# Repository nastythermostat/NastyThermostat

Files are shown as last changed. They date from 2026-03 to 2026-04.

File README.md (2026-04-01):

# NastyThermostat

**Mechanically control a Nest Gen2 thermostat — fully local, no cloud, no API.**

A Nest Gen2 thermostat that lost Google connectivity? NastyThermostat gives it a second life by physically rotating the dial using a stepper motor and GT2 belt — controlled by an ESP32-C6 with MQTT, Domoticz, and Home Assistant integration.

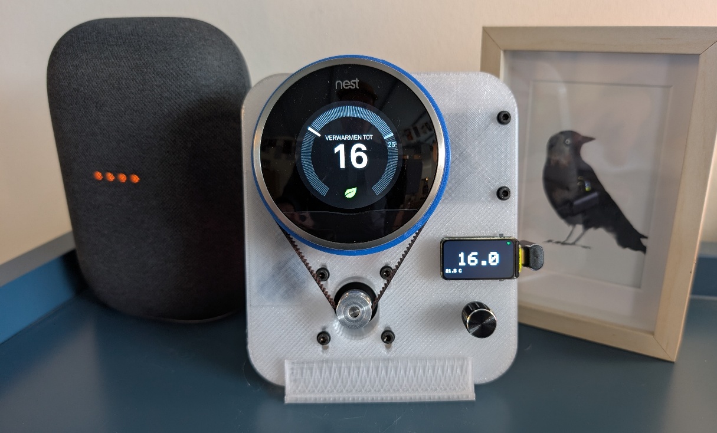
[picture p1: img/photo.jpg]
NastyThermostat hardware overview


▶️ **[Watch the video](https://youtu.be/sp1l5ZTAiks)**

---

## How it works

```
ESP32-C6  →  DRV8825 driver  →  NEMA17 stepper  →  GT2 belt  →  Nest dial
```

The ESP32-C6 reads a DS18B20 temperature sensor and receives setpoints via rotary encoder, MQTT, or HTTP API. It calculates how many steps to move and physically rotates the Nest dial to the target temperature.

---

## Quick start

| Step | Guide |
|---|---|
| **Assemble the hardware** | [→ Build guide](https://nastythermostat.cc/build) |
| **Print the 3D parts** | [→ 3D models](https://nastythermostat.cc/3d-models) |
| **Flash the firmware** | [→ Webflash (browser, no software needed)](https://nastythermostat.cc/webflash) |
| **Configure WiFi, MQTT & settings** | [→ Setup guide](https://nastythermostat.cc/setup) |
| **See it in action** | [→ YouTube video](https://youtu.be/sp1l5ZTAiks) |

---

## Features

- DS18B20 local temperature sensor
- Rotary encoder for manual control
- ST7789 TFT display (1.47")
- MQTT publish/subscribe (temperature + setpoint)
- Domoticz integration (IDX based)
- Home Assistant MQTT Discovery (automatic `climate` entity)
- HTTP REST API
- WiFiManager configuration portal (no code changes needed)
- Persistent settings (ESP32 Preferences)
- Stepper power management (auto-disable when idle)

---

## Parts list

**[→ Download full parts list with supplier links (Excel)](https://github.com/nastythermostat/NastyThermostat/raw/main/docs/Part_List.xlsx)**  
**[→ Build guide — wiring and assembly details](https://nastythermostat.cc/build)**

| # | Component | Qty | ~Price |
|---|---|---|---|
| 1 | ESP32-C6 dev board with 1.47" ST7789 display | 1 | €15.89 |
| 2 | DRV8825 stepper driver module | 1 | €1.69 |
| 3 | Stepper driver expansion board (4-channel) | 1 | €1.01 |
| 4 | NEMA17 stepper motor (1.8°, 17 Ncm, 1A, 23mm) | 1 | €9.76 |
| 5 | DS18B20 temperature sensor module | 1 | €1.83 |
| 6 | KY-040 rotary encoder | 1 | €1.55 |
| 7 | GT2 closed loop belt 320mm | 1 | €1.89 |
| 8 | GT2 pulley 20T, 5mm bore | 1 | €1.00 |
| 9 | 12V 3A power adapter (5.5×2.1mm) | 1 | €11.68 |
| 10 | DC-DC buck converter 12V → 5V 5A | 1 | €1.89 |
| 11 | USB-C 90° adapter | 1 | €2.25 |
| 12–15 | Cables (power, Dupont, stepper, USB-C/Micro-USB) | — | €6.79 |
| 16–18 | M3×8 screws, M3 washers, M2×8 screws | — | — |
| 19–21 | 3D printed: Nest pulley (138T), mounting plate, stand | — | — |

**Total electronics + mechanical: ~€55**

---

## Pin mapping

| Function | GPIO |
|---|---|
| TFT CS | 14 |
| TFT DC | 15 |
| TFT RST | 21 |
| TFT Backlight | 22 |
| TFT MOSI | 6 |
| TFT SCLK | 7 |
| Stepper STEP | 2 |
| Stepper DIR | 3 |
| Stepper ENABLE | 5 |
| Encoder CLK | 0 |
| Encoder DT | 1 |
| Encoder Button | 4 |
| DS18B20 | 9 |

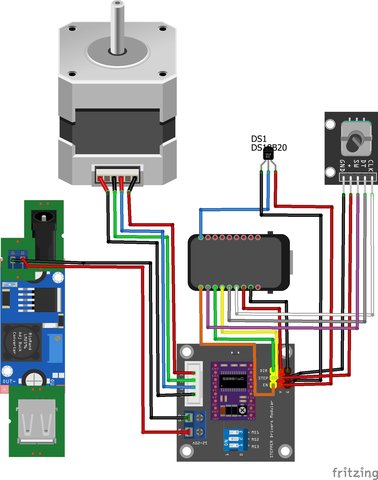
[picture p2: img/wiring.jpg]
Wiring diagram


---

## 3D printed parts

**[→ 3D models page with previews and download](https://nastythermostat.cc/3d-models)**  
**[→ Printables](https://www.printables.com/model/1659567-nastythermostat-3d-printed-parts-for-nest-gen2-ste)**  
**[→ Thingiverse](https://www.thingiverse.com/thing:7327205)**

STL files are in the [`/3d-models/`](3d-models/) folder. Print in PLA or PETG, 30% infill minimum.

| Part | Description |
|---|---|
| Nest pulley 138T | Attaches directly to the Nest dial ring |
| Motor mount | Mounts the NEMA17 to the base plate |
| Mounting plate | Base for all electronics and the Nest |
| Stand | Tilts the plate to the right angle |

---

## Flashing the firmware

**[→ Flash NastyThermostat via browser (no software needed)](https://nastythermostat.cc/webflash)**  
**[→ Full setup instructions](https://nastythermostat.cc/setup)**

The easiest way is via the browser — no software needed. Or build and upload with PlatformIO:

```bash
git clone https://github.com/nastythermostat/NastyThermostat.git
cd NastyThermostat
cp include/SecretsTemplate.h include/arduino_secrets.h
pio run --target upload
```

---

## Configuration

### First boot — WiFiManager portal

On first boot (or when WiFi is not found), the device creates an access point:

```
SSID:  NastyThermostatXXXXXX
URL:   http://192.168.4.1
```

Connect to this AP and open the portal to configure all settings.

| Setting | Description |
|---|---|
| **Device name** | Used for MQTT topics and AP SSID. Default: `NastyThermostatXXXXXX` |
| **MQTT server** | IP or hostname of your broker. Leave empty to disable MQTT. |
| **MQTT port** | Default: `1883` |
| **Domoticz IDX temperature** | Virtual sensor IDX for temperature. `0` = disabled. |
| **Domoticz IDX setpoint** | Virtual sensor IDX for setpoint. `0` = disabled. |
| **Domoticz gateway OUT mode** | `index` (default) = `domoticz/out/{idx}`. `flat` = `domoticz/out`, filtered by IDX. |
| **Homing after receiving setpoint** | `on` = full homing before move (accurate). `off` = small jiggle (faster, less wear). |
| **Home Assistant MQTT Discovery** | `on` = auto-creates a climate entity in HA. |
| **HTTP API token** | Required for POST requests. Leave empty to disable writes. |
| **MQTT publish interval** | How often temperature is published (seconds). Default: `30`. |

**[→ Full setup instructions with screenshots](https://nastythermostat.cc/setup)**

Re-open the portal anytime: **Menu → 5. WiFi setup → Start WiFi portal**, or hold the encoder button for 5 seconds at boot.

---

## MQTT topics

Topics use the device name (configurable in portal). Default: `NastyThermostatXXXXXX`

| Topic | Direction | Description |
|---|---|---|
| `{deviceName}/out/temp` | Publish | Current temperature (°C) |
| `{deviceName}/out/setpoint` | Publish (retained) | Current setpoint (°C) |
| `{deviceName}/in/setpoint` | Subscribe | Set new setpoint (float, e.g. `21.5`) |
| `{deviceName}/out/availability` | Publish (retained) | `online` / `offline` (LWT) |
| `{deviceName}/out/action` | Publish (retained) | `heating` or `idle` |
| `{deviceName}/out/mode` | Publish (retained) | `heat` (fixed, for HA compatibility) |

### Domoticz

```
Subscribe: domoticz/out/{idxSetpoint}   (index mode, default)
           domoticz/out                  (flat mode, filtered by idx)
Publish:   domoticz/in
```

### Home Assistant

With MQTT Discovery enabled, a `climate` entity is automatically created — no manual YAML needed.

---

## HTTP API

The device hosts a REST API on port 80.

### GET /api

```bash
curl http://192.168.x.x/api
```

```json
{
  "device_name": "NastyThermostat123456",
  "setpoint": 20.5,
  "temperature": 19.8,
  "offset": 0.0,
  "stepSize": 0.1,
  "motor_position": 14420,
  "steps_per_degree": 856.0,
  "mqtt_enabled": true
}
```

### POST /api

Requires token (set in WiFiManager portal).

```bash
curl -X POST http://192.168.x.x/api \
  -H "Content-Type: application/json" \
  -d '{"token":"yourtoken","setpoint":21.0}'
```

| Field | Type | Description |
|---|---|---|
| `token` | string | **Required**. API token from portal. |
| `setpoint` | float | New setpoint in °C (9.0–32.0) |
| `offset` | float | Temperature offset correction (−10.0 to 10.0) |
| `stepSize` | float | Encoder step size: `0.1`, `0.2`, `0.5` or `1.0` |
| `steps_per_degree` | float | Calibration: microsteps per °C (10–2000) |

---

## On-device menu

Press the encoder button to open the menu. Rotate to navigate, press to select.

| Item | Description |
|---|---|
| 1. Homing | Perform manual homing (moves to mechanical stop, resets position to 0) |
| 2. Temperature offset | Correct DS18B20 reading ±10°C, press to save |
| 3. Steps/degree | Calibration: microsteps per °C, press to save |
| 4. Step size | Encoder resolution: 0.1 / 0.2 / 0.5 / 1.0°C |
| 5. WiFi setup | Open WiFiManager portal (device reboots into AP mode) |
| 6. Status | Shows firmware version, IP address, MQTT status |
| 7. Back | Return to main screen |

---

## Display

The main screen shows:
- **Large center**: current setpoint (°C)
- **Bottom left**: measured temperature (°C)
- **Top right**: WiFi status icon — green = connected, red = disconnected
- **Background**: orange when heating (setpoint > temperature), black when idle

Screen auto-off after 15 seconds of inactivity. Encoder movement or motor activity wakes the display.

---

## Calibration

Default: **856 microsteps/°C** (= 26.75 full-steps, based on 138T/20T pulley ratio at 1/32 microstepping).

If your Nest doesn't hit the right temperatures, adjust via:
- On-device menu → **3. Steps/degree**
- HTTP API: `{"token":"...","steps_per_degree": 856.0}`

---

## Serial commands

Connect at **115200 baud**.

| Command | Description |
|---|---|
| `?` or `h` | Show status banner (IP, MQTT broker, topics) |
| `i` | Show WiFi and MQTT connection status |

---

## Troubleshooting

**Motor moves but Nest temperature is wrong**  
→ Adjust Steps/degree in menu or via API. Start with small increments.

**WiFi not connecting**  
→ Check Serial Monitor at 115200 baud. Re-open portal via menu → **5. WiFi setup**.

**MQTT not connecting**  
→ Verify broker IP and port in portal. Check Serial Monitor output.

**DS18B20 reads 0°C or wrong temperature**  
→ Check wiring on GPIO9. Use temperature offset in menu to correct.

**[→ Setup guide — more help and troubleshooting](https://nastythermostat.cc/setup)**

---

## License

MIT — see [LICENSE](LICENSE)

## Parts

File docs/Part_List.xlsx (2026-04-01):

Item No. | Category | Component Name | Description | Quantity | Unit Price (€) | Notes | Info/Link | Supplier
1 | Electronics | ESP32-C6 LCD 1.47 | ESP32-C6 dev board with 1.47” Waveshare | 1 | €15.89 | Main controller | https://www.waveshare.com/esp32-c6-lcd-1.47.htm | Amazon/AliExpress (https://nl.aliexpress.com/item/1005008207326324.html)
2 | Electronics | DRV8825 Stepper Driver | Microstepping driver module (heatsink included) | 1 | €1.69 | Stepper driver | AliExpress (https://nl.aliexpress.com/item/1005009949890484.html) | Amazon/AliExpress (https://www.amazon.nl/DollaTek-Stappenmotor-StepStick-stappenmotor-3D-printer/dp/B07DK6QMKG/)
3 | Electronics | Stepper Driver Expansion Board | 4-channel driver carrier board | 1 | €1.01 | 5V & GND distribution | AliExpress (https://nl.aliexpress.com/item/1005006070691966.html) | Amazon/AliExpress
4 | Electronics | NEMA17 Stepper Motor | 1.8°, 17 Ncm, 1A, 23mm body length | 1 | €9.76 | Compact motor | Amazon.nl (https://www.amazon.nl/dp/B0B93PNYCP?ref_=ppx_hzsearch_conn_dt_b_fed_asin_title_1) | Amazon/AliExpress
5 | Electronics | DS18B20 Temperature Sensor | Digital 1-Wire temperature module | 1 | €1.83 | Room temperature | AliExpress (https://nl.aliexpress.com/item/1005009580730409.html) | Amazon/AliExpress
6 | Electronics | KY-040 Rotary Encoder | 360° encoder with push button | 1 | €1.55 | User control | AliExpress (https://nl.aliexpress.com/item/1005009578504178.html) | Amazon/AliExpress
7 | Mechanical | GT2 Belt 320mm | Closed loop 2GT-320-6mm belt | 1 | €1.89 | Final belt length | AliExpress (https://nl.aliexpress.com/item/1005008778076494.html) | Amazon/AliExpress
8 | Mechanical | GT2 Pulley 20T | 20 teeth pulley, 5mm bore | 1 | €1.00 | On stepper motor | AliExpress (https://nl.aliexpress.com/item/32434506931.html) | Amazon/AliExpress
9 | Power | 12V 3A Power Adapter | 5.5x2.1mm DC output adapter | 1 | €11.68 | Main supply | Amazon.nl | Amazon/AliExpress
10 | Power | DC-DC Buck Converter | 12V to 5V 5A step-down module | 1 | €1.89 | Powers ESP32 | Amazon.nl (https://www.amazon.nl/Heemol-Converter-Module-Step-Down-Voeding/dp/B0BCV6GRH5) | Amazon/AliExpress
11 | Power | Adapter USB-C 90° Adapter | Power the ESP32 | 1 | €2.25 | Powers ESP32 | AliExpress (https://nl.aliexpress.com/item/1005007802183944.html) | Amazon/AliExpress
12 | Wiring | 12V Power Cable (thick) | 14cm red/black cable for stepper 12V supply | 1 | €1.00 | Adapter → driver |  | Amazon/AliExpress
13 | Wiring | Dupont Jumper Wires pack | 10 cm Female to Female | 1 | €1.50 | GND wiring | Amazon.nl (https://www.amazon.nl/dp/B0BJDW1S4Z?ref=ppx_yo2ov_dt_b_fed_asin_title) | Amazon/AliExpress
14 | Wiring | 2 in 1 USB C - Micro USB Cable | 0.2m Split cable | 1 | €3.29 | 5v supply for Nest and ESP32 | AliExpress (https://nl.aliexpress.com/item/1005008316990883.html) | Amazon/AliExpress
15 | Wiring | Stepper Moter Cable | 10-15cm JST XH2.54mm female (black, green, blue, red) | 1 | €1.00 | Stepper driver to motor |  | Amazon/AliExpress
16 | Hardware | M3x8 Screws | Metric screw, 8mm length | 8 |  | Mounting
17 | Hardware | M3 Washers | M3 flat washer | 6 |  | Mounting
18 | Hardware | M2x8 Screws | Metric screw, 8mm length | 2 |  | Mounting
19 | 3D Print | GT2 Pulley 138T | Custom pulley for Nest thermostat | 1 |  | Mounted on Nest | https://nastythermostat.cc/3d
20 | 3D Print | Mounting Plate | Baseplate for electronics and Nest mounting | 1 |  | Mounting | https://nastythermostat.cc/3d
21 | 3d Print | Stand | Stand for the Mounting Plate | 1 |  | Stand | https://nastythermostat.cc/3d

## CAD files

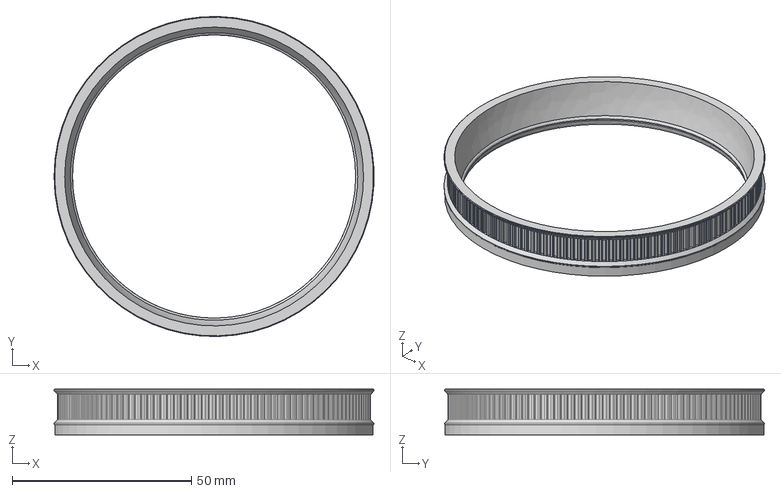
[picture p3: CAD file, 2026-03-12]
3d-models/Files/GT2 Pulley138.step
89.3 x 89.3 x 12.8 mm

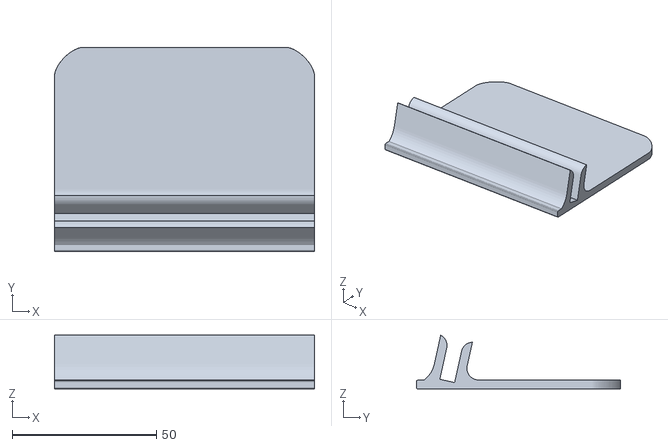
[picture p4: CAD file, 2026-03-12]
3d-models/Files/Stand.stl
90.0 x 70.8 x 18.6

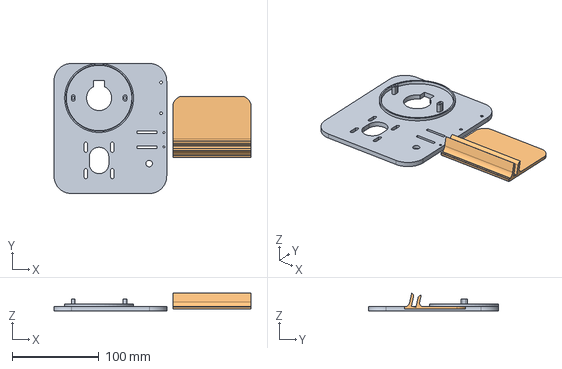
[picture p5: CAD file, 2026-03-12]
3d-models/Files/Nasty_Mounting.step
227.1 x 150.0 x 20.6 mm

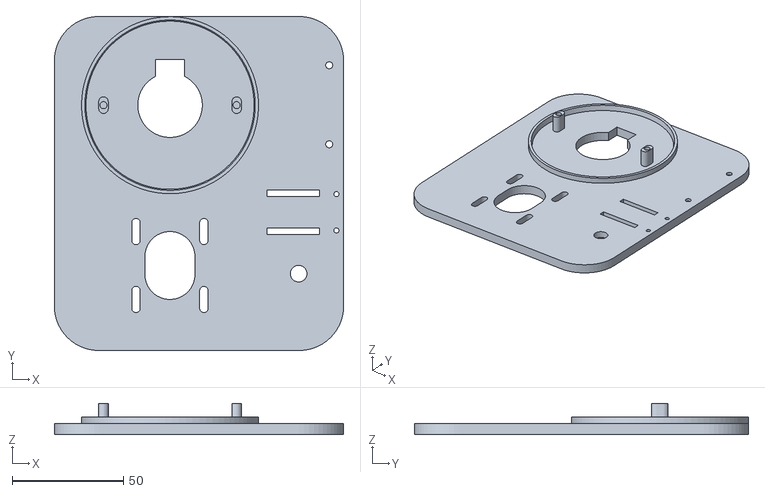
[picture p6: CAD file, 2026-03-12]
3d-models/Files/Mounting Plate.stl
130.0 x 150.0 x 14.0

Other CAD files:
3d-models/Files/GT2 Pulley138.f3d
3d-models/Files/GT2 Pulley138.stl
3d-models/Files/Nasty_Mounting.f3d

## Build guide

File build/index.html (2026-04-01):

NastyThermostat.cc

On this page

Assembly Guide

# Build your NastyThermostat

Step-by-step instructions for assembling the ESP32-C6 Nest stepper controller.

NastyThermostat overview

01 — Parts & Tools

Gather all parts and tools before you start. Check the list below.

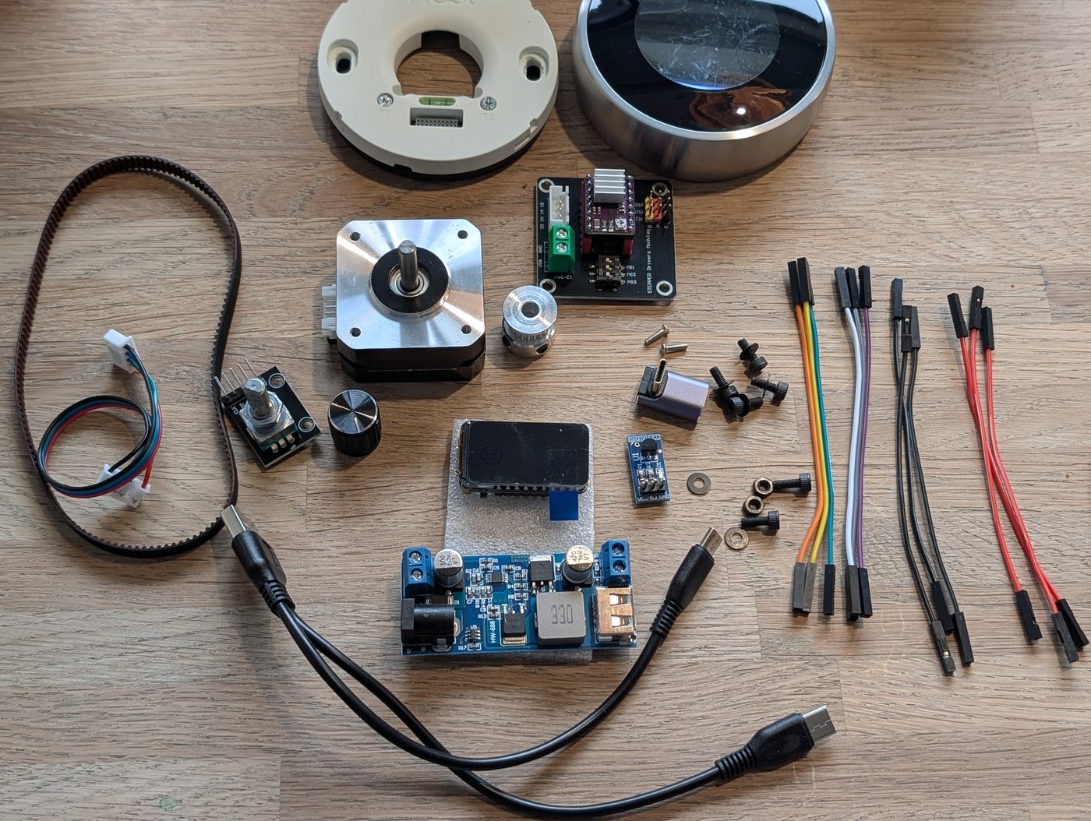
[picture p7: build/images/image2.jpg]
All parts overview


Tools required

Screwdriver Scissors Hot glue gun Hex keys Multimeter

⬇ Download parts list (Excel) (https://github.com/nastythermostat/NastyThermostat/raw/main/docs/Part_List.xlsx)

Component | Description | Qty
ESP32-C6 LCD 1.47 | ESP32-C6 dev board with 1.47" Waveshare display | 1
DRV8825 Stepper Driver | Microstepping driver module (heatsink included) | 1
Stepper Driver Expansion Board | 4-channel driver carrier board | 1
NEMA17 Stepper Motor | 1.8°, 17 Ncm, 1A, 23mm body length | 1
DS18B20 Temperature Sensor | Digital 1-Wire temperature module | 1
KY-040 Rotary Encoder | 360° encoder with push button | 1
GT2 Belt 320mm | Closed loop 2GT-320-6mm belt | 1
GT2 Pulley 20T | 20 teeth pulley, 5mm bore | 1
12V 3A Power Adapter | 5.5x2.1mm DC output adapter | 1
DC-DC Buck Converter | 12V to 5V 5A step-down module | 1
USB-C 90° Adapter | Power the ESP32 | 1
12V Power Cable (thick) | 14cm red/black cable for stepper 12V supply | 1
Dupont Jumper Wires pack | 10 cm Female to Female | 1
2 in 1 USB C - Micro USB Cable | 0.2m Split cable | 1
Stepper Motor Cable | 10-15cm JST XH2.54mm female (black, green, blue, red) | 1
M3x8 Screws | Metric screw, 8mm length | 8
M3 Washers | M3 flat washer | 6
M2x8 Screws | Metric screw, 8mm length | 2
GT2 Pulley 138T 3D PRINT | Custom pulley for Nest thermostat | 1
Mounting Plate 3D PRINT | Baseplate for electronics and Nest mounting | 1
Stand 3D PRINT | Stand for the Mounting Plate | 1

💡 Lay out all parts in an organised way before you start. This prevents confusion during assembly.

02 — Wiring Diagram

The steps below explain how to connect each component and which cables are needed. Below is a complete overview.

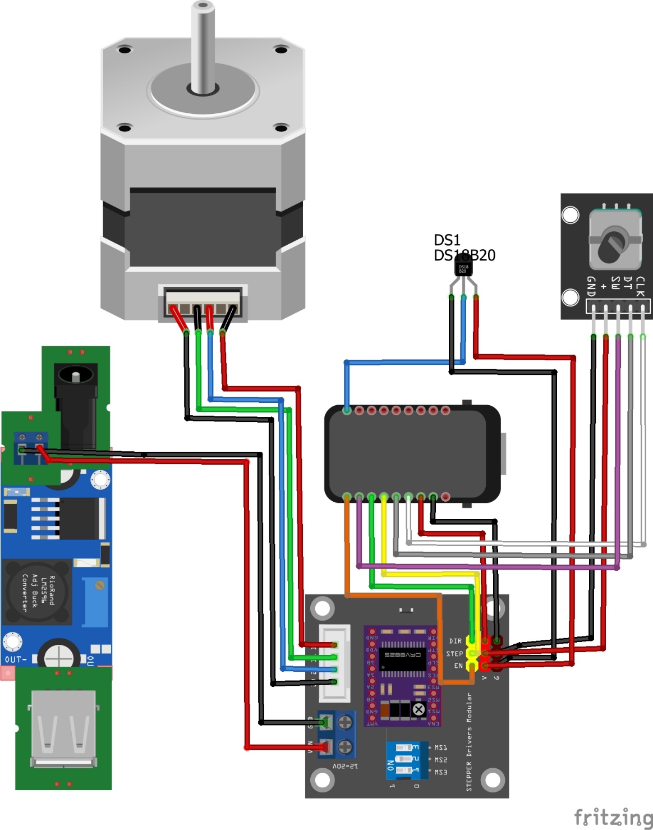
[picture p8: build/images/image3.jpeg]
Wiring diagram


03 — Nest Baseplate

1. Remove the outer front cover of the Nest, leaving only the Nest baseplate.
2. The 3D-printed mounting plate has 2 oval protruding pieces with a hole in them.
3. Place the Nest on top and secure it with 2 M3 bolts.

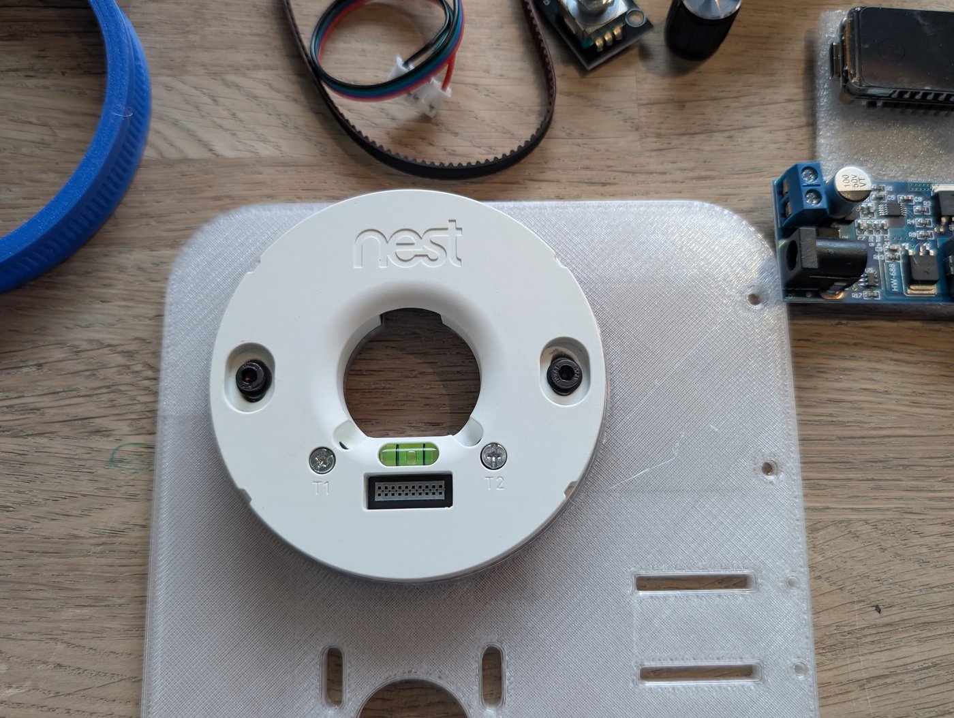
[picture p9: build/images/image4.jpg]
Nest baseplate


04 — Mounting Components on Baseplate

The white 3D-printed frame is the base on which all electronics are mounted. Place the frame flat in front of you.

STEP 01

### Buck Converter & Temperature Sensor

Place the DC-DC Buck Converter and the DS18B20 Temperature Sensor and secure them with hot glue.

⚠ USB port must face upward.

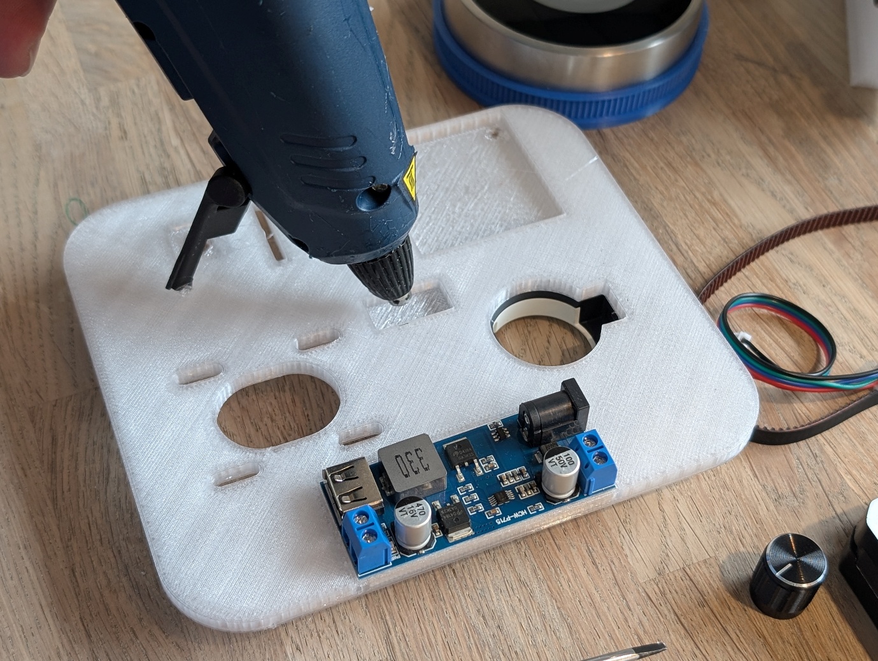
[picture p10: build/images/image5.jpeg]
Step 1a
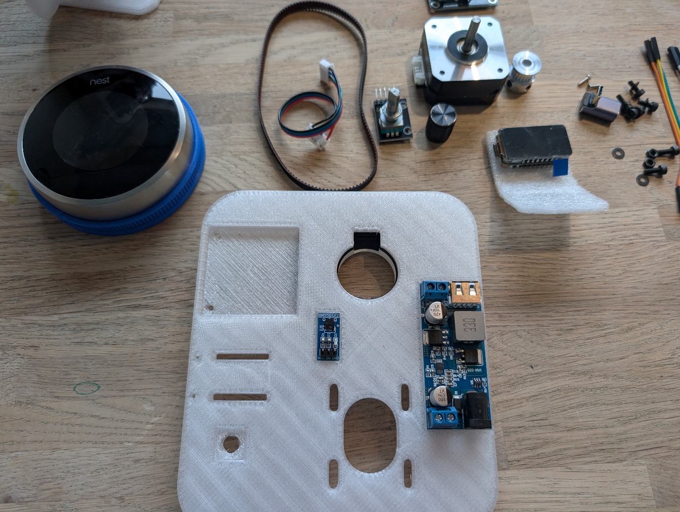
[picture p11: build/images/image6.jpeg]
Step 1b
 

STEP 02

### Stepper Driver Expansion Board

Mount the Stepper Driver Expansion Board and secure it with 2 bolts, 2 washers and 2 nuts. Make sure to place the DRV8825 Stepper Driver in the correct orientation on the expansion board. See photo.

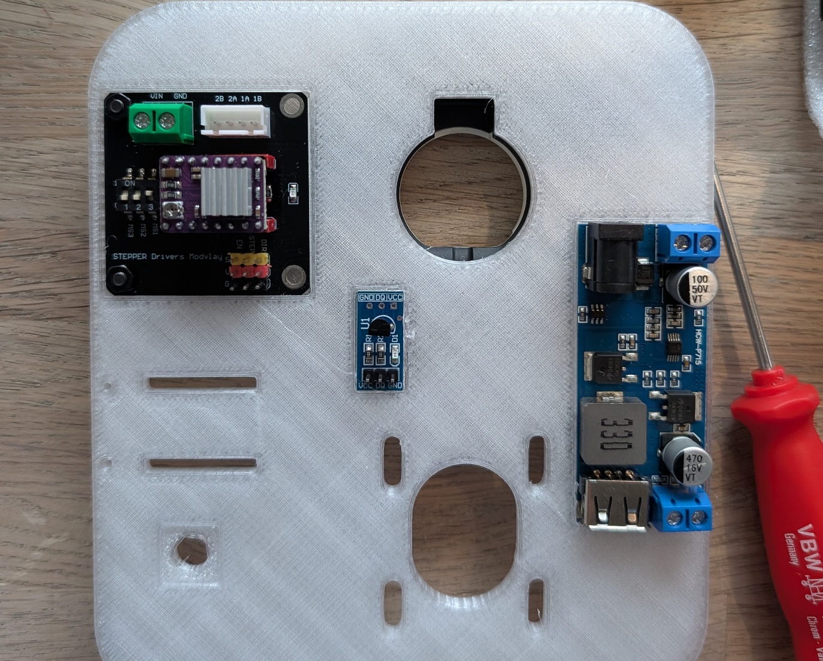
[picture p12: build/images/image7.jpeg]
Step 2


STEP 03

### 12V Power Wires

Attach the 2 thicker wires (14cm) for positive and negative of the 12V stepper driver supply, and secure them at the top with hot glue.

Step 3

STEP 04

### Jumper Cables — Stepper Driver Board

Before adding the other components, we start with the jumper cables. First, connect the jumper cables to the Stepper Driver Expansion Board.

Left: orange (EN), yellow (STEP), green (DIR). Below that 3 red jumper wires and at the bottom 3 black jumper wires.

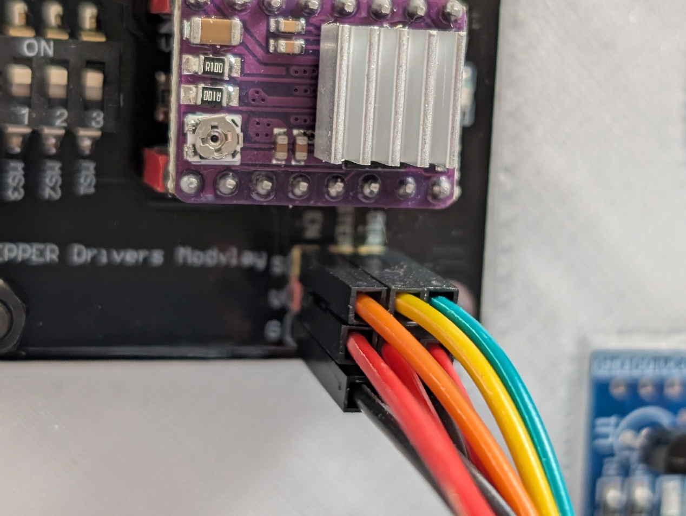
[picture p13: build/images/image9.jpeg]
Step 4


STEP 05

### Jumper Cables — DS18B20 Temperature Sensor

Next, connect the jumper cables to the DS18B20 Temperature Sensor: Red (VCC), blue (DQ), black (GND).

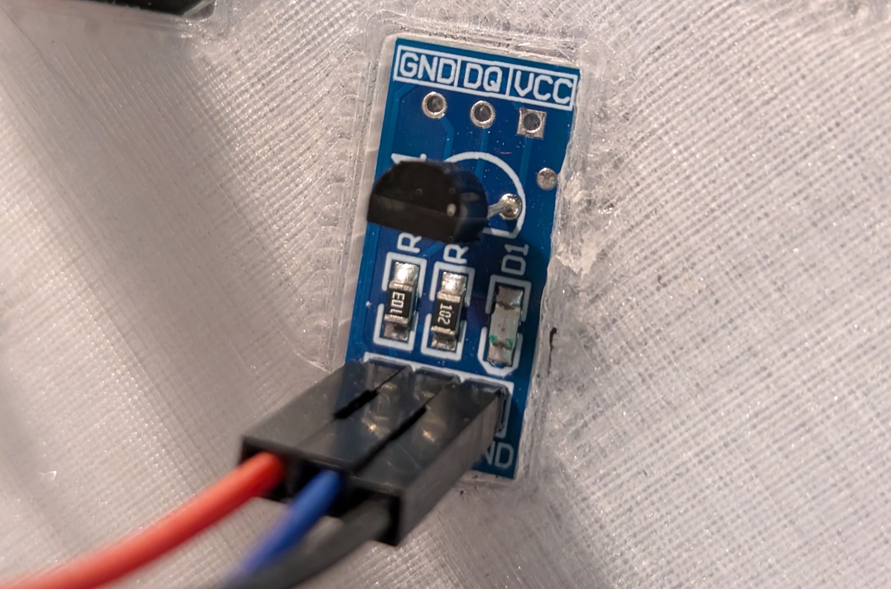
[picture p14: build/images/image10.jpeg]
Step 5


STEP 06

### Jumper Cables — KY-040 Rotary Encoder

Now take the KY-040 Rotary Encoder and connect the jumper wires: Black (GND), red (VCC), purple (SW), grey (DT), white (CLK).

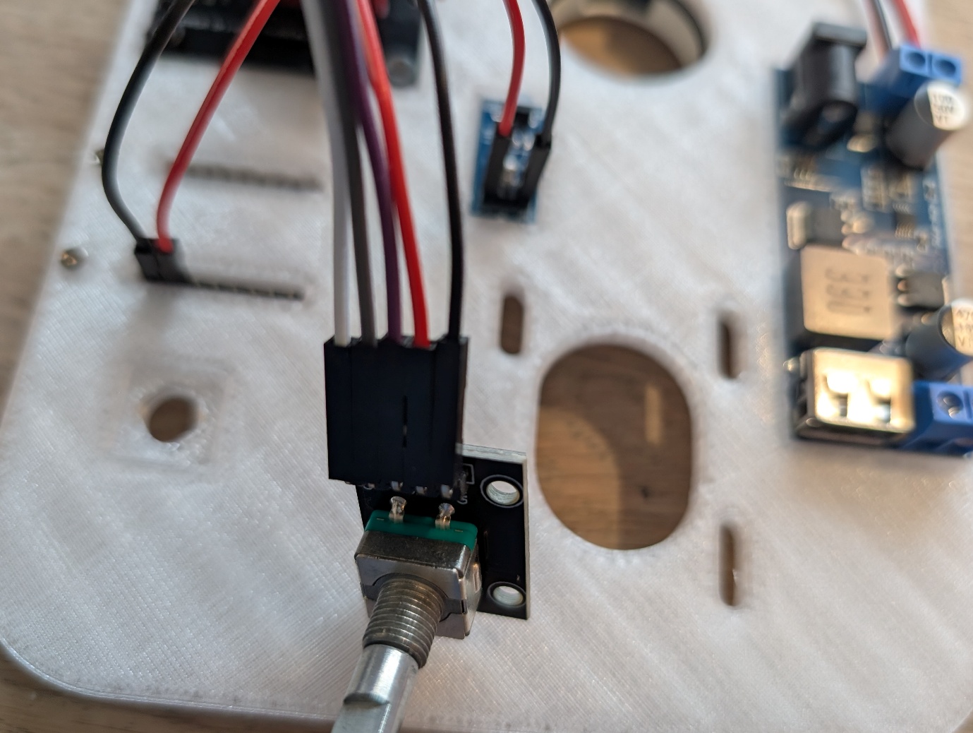
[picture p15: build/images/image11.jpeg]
Step 6


STEP 07

### Mount ESP32-C6 & Connect Wires

Now mount the ESP32-C6 LCD 1.47. The USB port faces outward and is secured with M2x8 bolts. Then connect the jumper wires.

⚠ Do not use the 5V pin!

Wire | ESP32 Pin | Connects to | Label
Black | GND | Stepper Driver Expansion Board | G
Red | 3V3 | Stepper Driver Expansion Board | V
White | 0 | KY-040 Rotary Encoder | CLK
Grey | 1 | KY-040 Rotary Encoder | DT
Yellow | 2 | Stepper Driver Expansion Board | STEP
Green | 3 | Stepper Driver Expansion Board | DIR
Purple | 4 | KY-040 Rotary Encoder | SW
Orange | 5 | Stepper Driver Expansion Board | EN
Blue | 9 | DS18B20 Temperature Sensor | DQ

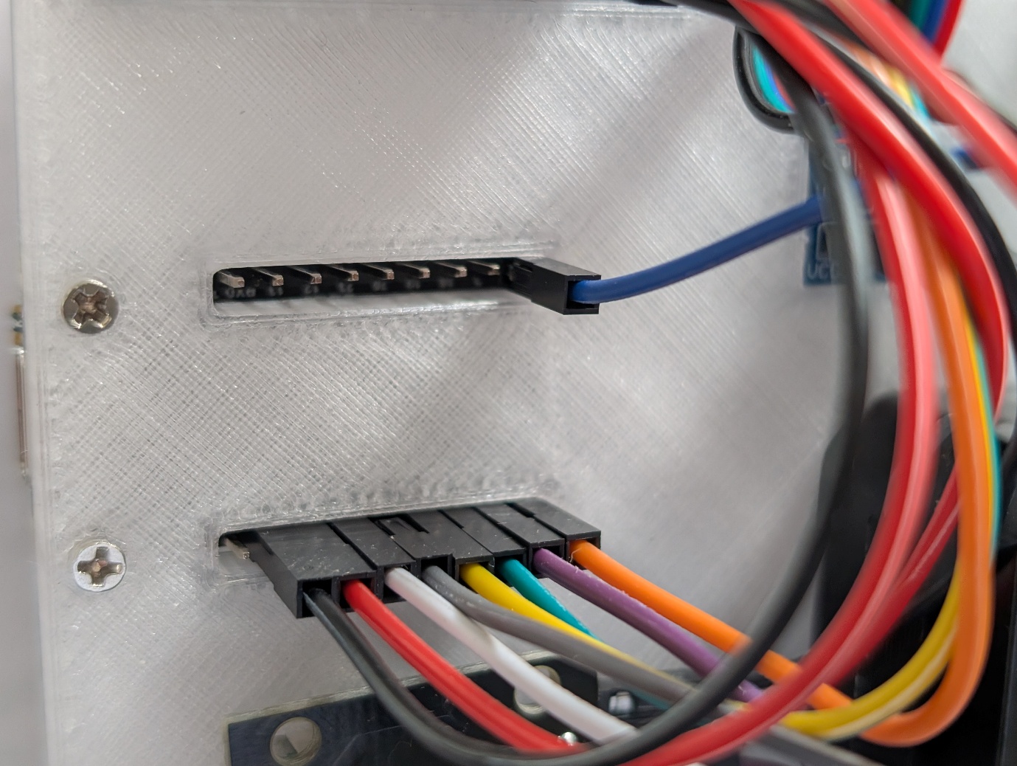
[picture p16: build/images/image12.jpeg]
Step 7 wiring


STEP 08

### Power On Test

Now connect the USB cable to the ESP32 and plug the 12V adapter into the DC-DC Buck Converter. LEDs should now light up on the DC-DC Buck Converter, DS18B20 Temperature Sensor and Stepper Driver Expansion Board.

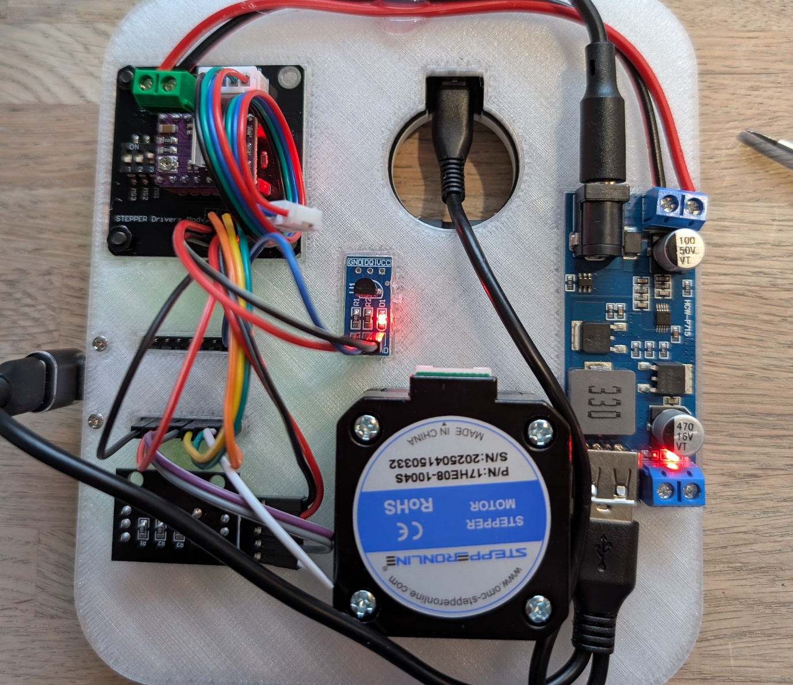
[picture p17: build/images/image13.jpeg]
Step 8 power on


05 — Gears and Belt

STEP 01

### Mount the Stepper Motor

Flip the baseplate and mount the stepper motor. Use 4x M3x8 bolts and 4 M3 washers. Do not fully tighten the bolts so you can slide the stepper motor back and forth.

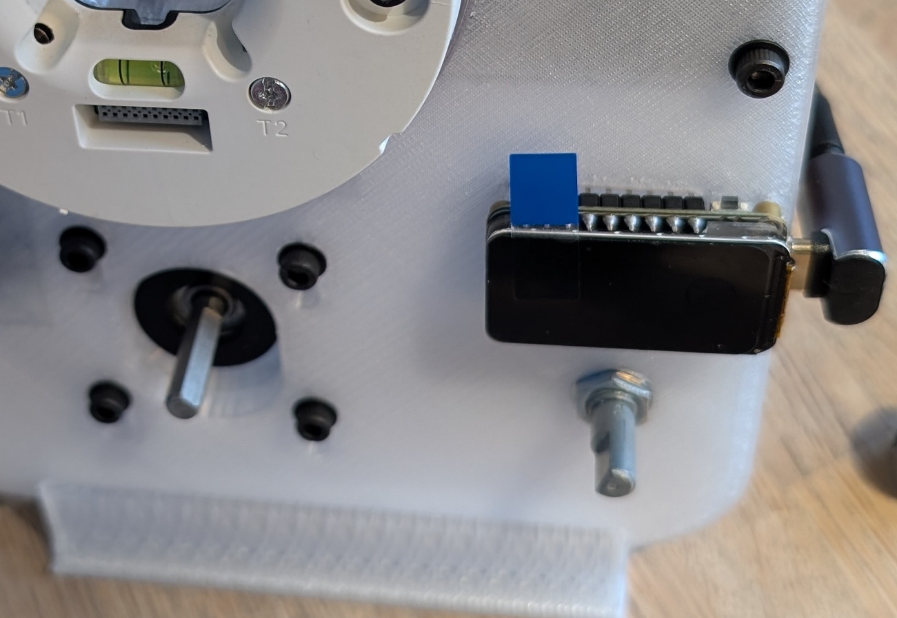
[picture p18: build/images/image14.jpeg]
Mount stepper motor


STEP 02

### Attach the Large Gear to the Nest

Apply thin double-sided tape at 3 points on the large 3D-printed gear and press it onto the bottom of the metal Nest ring. Then place it onto the already mounted Nest wallplate.

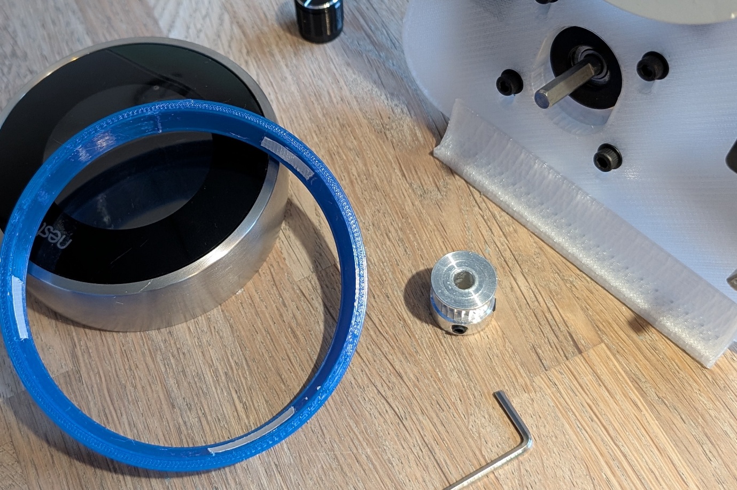
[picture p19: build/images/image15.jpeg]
Attach gear 1
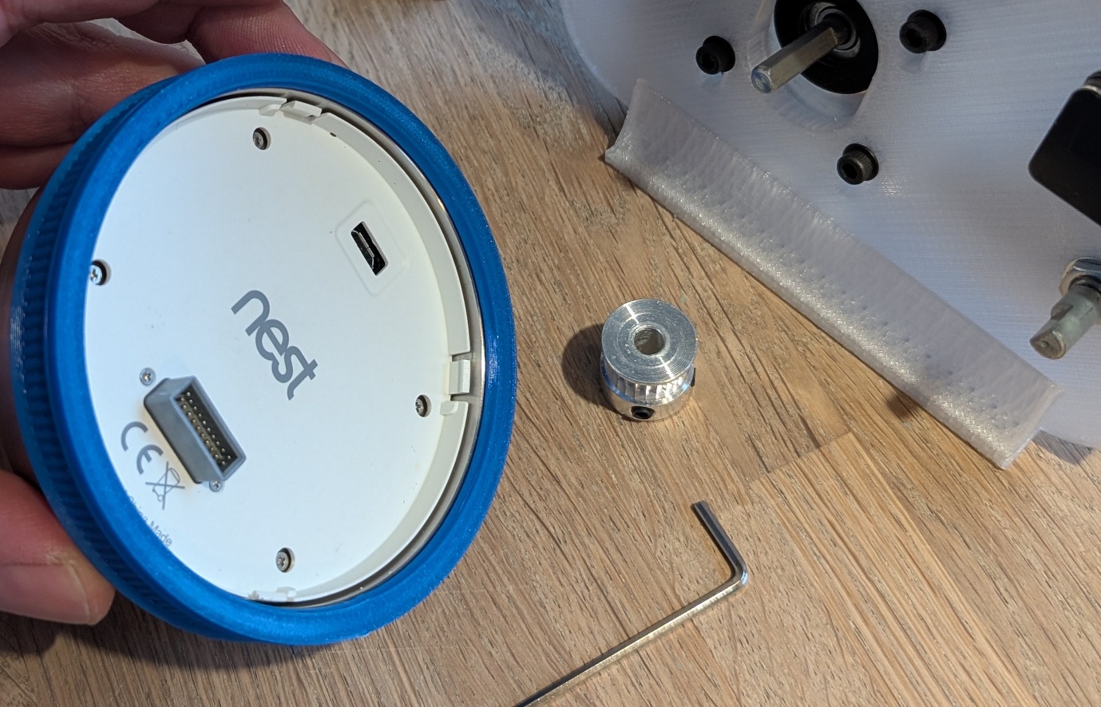
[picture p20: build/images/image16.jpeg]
Attach gear 2
 

STEP 03

### Mount the Pulley on the Stepper

Mount the pulley onto the stepper motor shaft using the hex key.

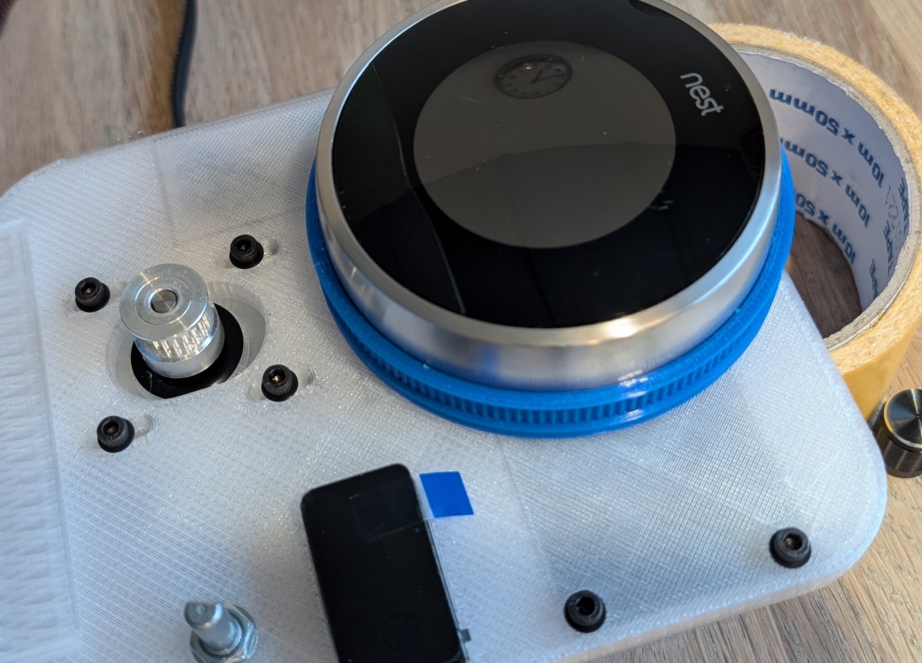
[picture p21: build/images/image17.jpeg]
Mount pulley


STEP 04

### Install and Tension the Belt

Place the belt over both pulleys. The stepper motor needs to be slid upward for this. Once the belt is in place, carefully tension it by sliding the motor downward and tightening the bolts.

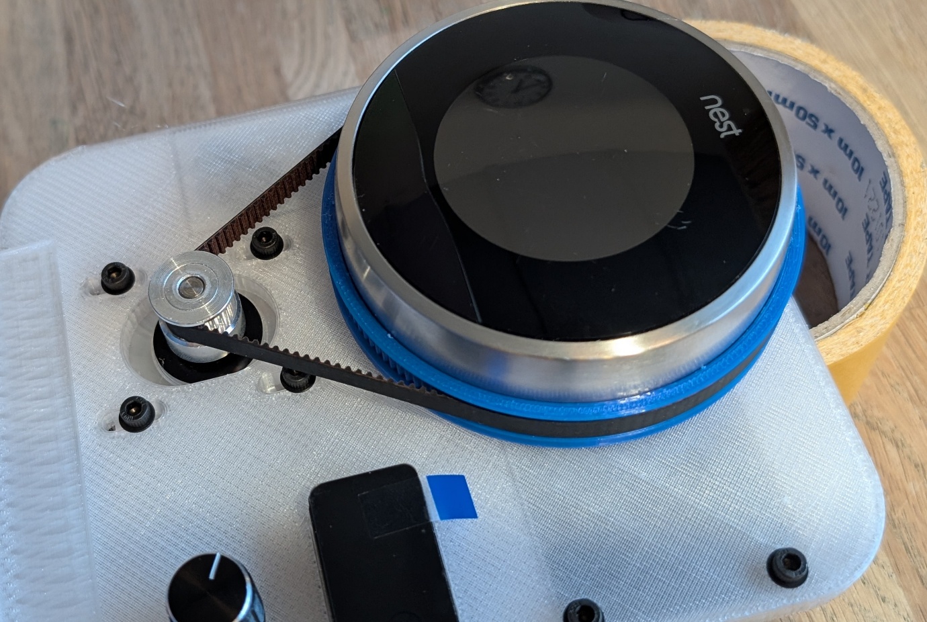
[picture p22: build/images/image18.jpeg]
Belt installation


06 — Connecting the Stepper Motor

The stepper motor still needs to be connected to the Stepper Driver Expansion Board. The board is labeled 2b, 2a, 1a, 1b. The pin order may vary per motor. For this stepper motor, connect as follows:

🔌 black → 2b · blue → 2a · green → 1a · red → 1b
The stepper motor has 6 connectors; the outermost and innermost ones are used.
Left: black · left middle: green · right middle: blue · right: red

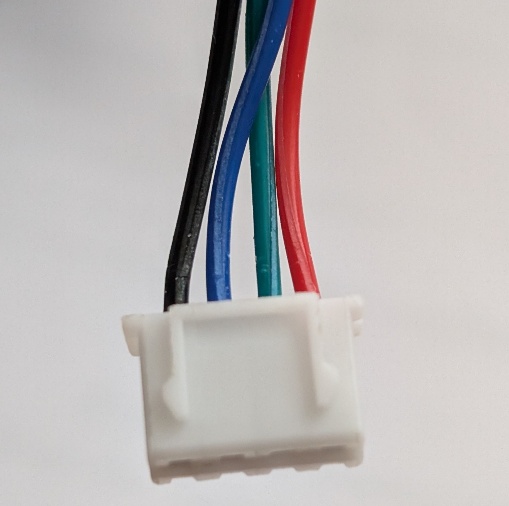
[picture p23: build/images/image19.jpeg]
Stepper motor connection
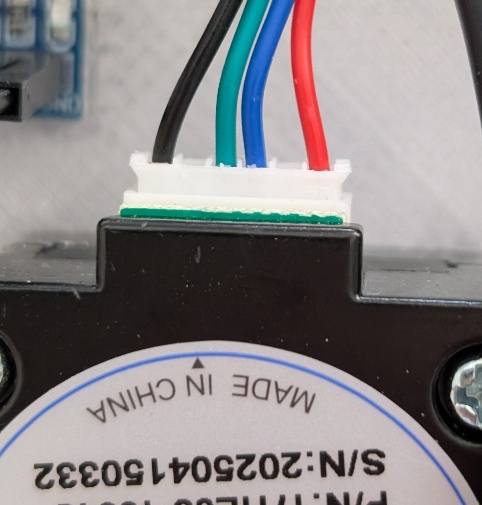
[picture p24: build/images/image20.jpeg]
Stepper motor connection detail
 

07 — Microstepping & Current Limiting

## Microstepping

A standard NEMA17 motor has 200 steps per full revolution. With microstepping, the driver divides each step into smaller increments. At 1/32 microstepping, each step is split into 32 micro-steps, resulting in 6400 steps per revolution. This produces smoother and quieter movement.

Set the microstepping to 1/32 by setting all 3 mini jumpers to 1.

MS1 | MS2 | MS3 | Microsteps
Low | Low | Low | Full step
High | Low | Low | Half step
Low | High | Low | 1/4 step
High | High | Low | 1/8 step
Low | Low | High | 1/16 step
High | Low | High | 1/32 step ← use this
Low | High | High | 1/32 step
High | High | High | 1/32 step

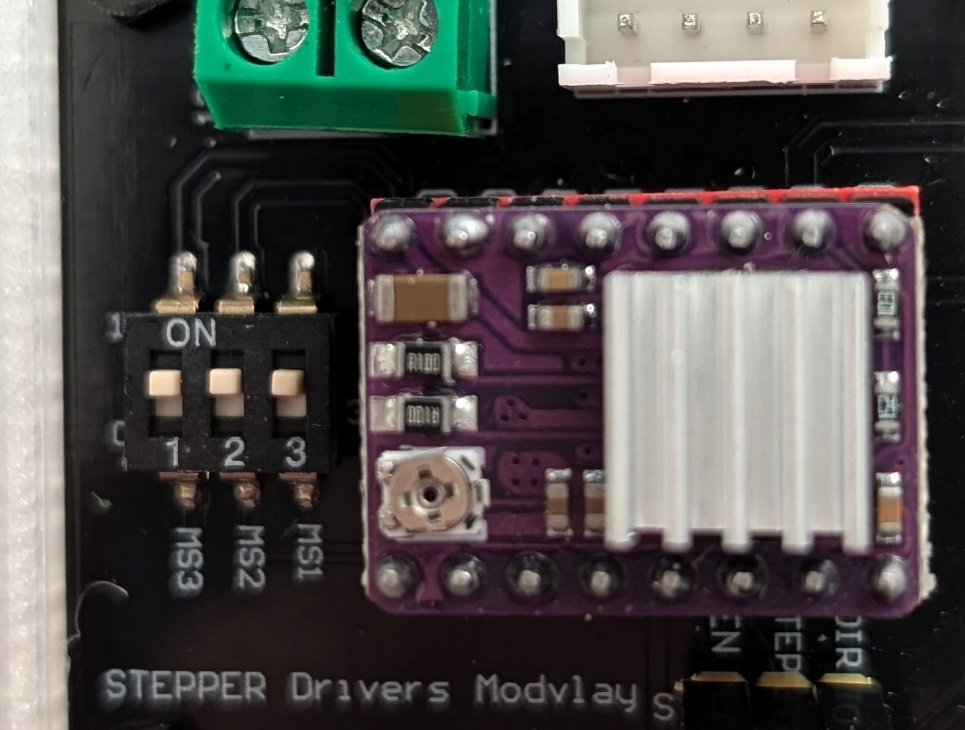
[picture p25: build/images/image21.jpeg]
Microstepping jumpers


## Current Limiting

⚠ Make sure the LED on the Stepper Driver Expansion Board is on before following the steps below.

The DRV8825 limits the current to the motor via an internal current-limiting circuit. You set how much current the motor receives via a small trimpot on the DRV8825.

Too little current = missed steps. Too much = overheating.

The rated current is printed on the label of your stepper motor (e.g. 1A or 1.5A). Set the current to 70–90% of this value.

📐 I use a Vref of 0.45V, which is on the high side but works well.
Vref = (90% of 1A) × 0.5 = 0.45V

Make sure the system is fully powered on. Use a small Phillips screwdriver. When you hold the positive probe of your multimeter against the screwdriver and the negative probe on GND, you can see the current Vref live.

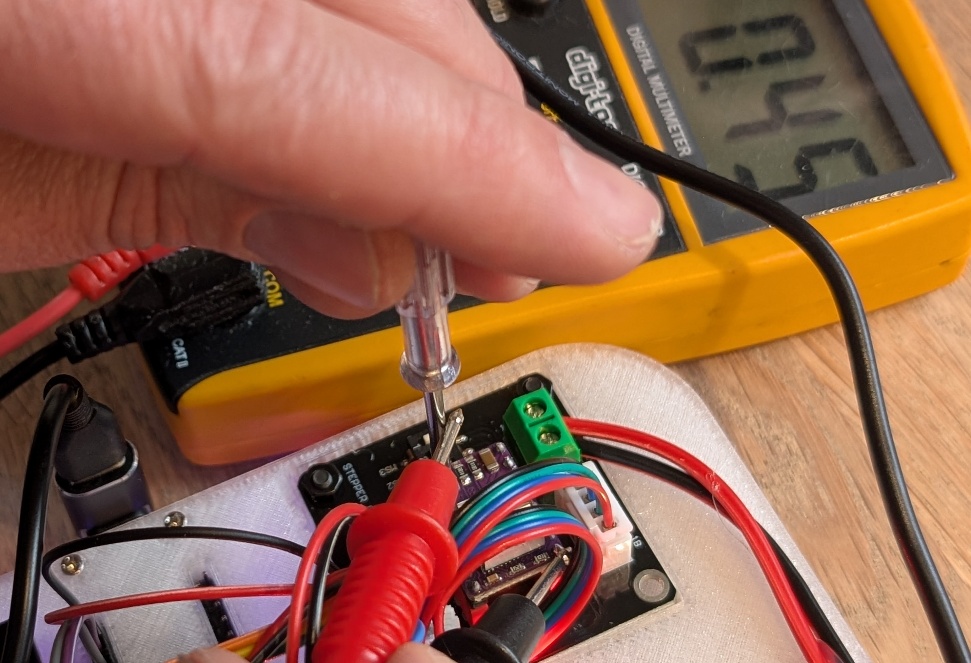
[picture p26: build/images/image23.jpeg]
Measuring Vref
Trimpot adjustment 

08 — Final Steps

ROTARY ENCODER

### Secure the Rotary Encoder

Before the firmware can be flashed to the ESP, the KY-040 Rotary Encoder must be secured. Simply insert it through the hole and tighten the ring and nut. Finally, press the knob onto the rotary encoder.

CHECK

### Final Cable Check

Then carefully check that all cables are connected and place the baseplate in the Stand.

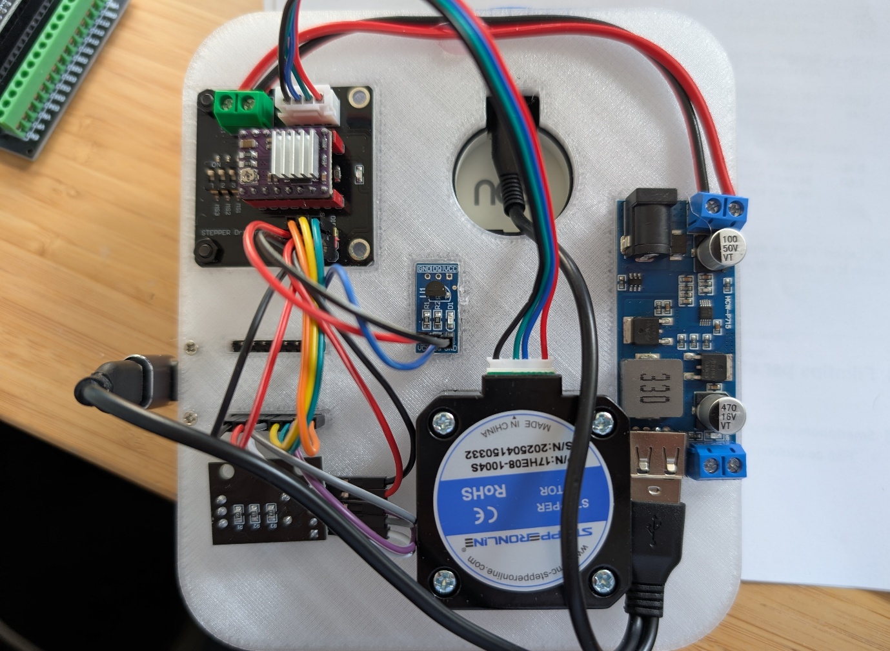
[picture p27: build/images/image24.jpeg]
Final assembly


FIRMWARE

### Flash Firmware via USB

Connect the USB cable and go to nastythermostat.cc/webflash — then follow the steps in the webflasher to install the firmware.

💡 On Windows 11 no driver installation is needed. If the device is not recognised, find the driver at waveshare.com (https://www.waveshare.com/wiki/ESP32-C6-LCD-1.47).

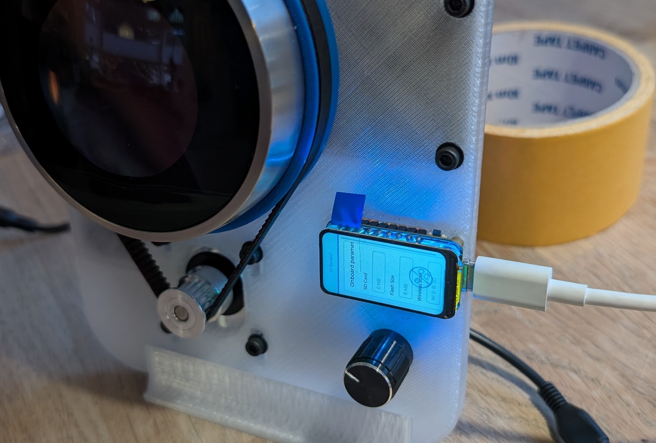
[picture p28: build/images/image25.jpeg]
Firmware flashing


▶ Watch: Flash firmware & configure settings (https://youtu.be/RYTQFML2HiY)

NastyThermostat — nastythermostat.cc Build guide (https://nastythermostat.cc/build) · 3D models (https://nastythermostat.cc/3d-models) · Setup & Flash (https://nastythermostat.cc/setup) · Webflash (https://nastythermostat.cc/webflash) · GitHub (https://github.com/nastythermostat/NastyThermostat)

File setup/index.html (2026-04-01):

NastyThermostat.cc

On this page

Setup Guide

# Firmware & Configuration

Install the firmware via the webflasher and configure WiFi, MQTT and all other settings.

▶ Watch: Flash firmware & configure settings (https://youtu.be/RYTQFML2HiY)

💡 Required browser: Google Chrome or Microsoft Edge. Firefox and Safari do not support the Web Serial API.

Part 1 — Installing the Firmware

STEP 01

### Open the webflasher

Connect the NastyThermostat to your computer via USB. Then open Chrome or Edge and go to:

https://nastythermostat.cc/webflash

Click the Connect button.

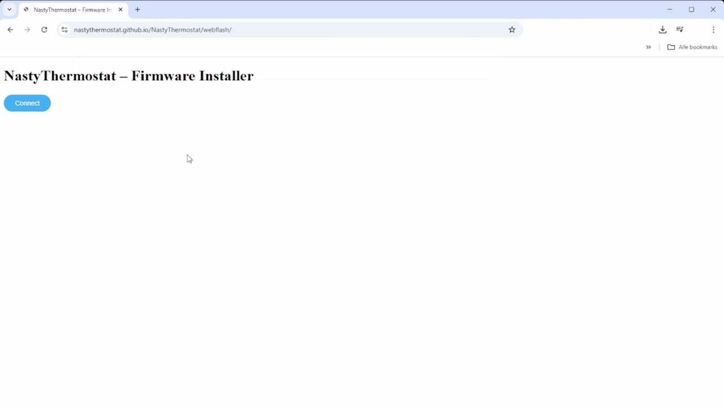
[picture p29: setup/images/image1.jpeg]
Webflasher — Connect button


STEP 02

### Select the device

A pop-up appears with available serial ports. Select the port of the ESP32-C6 (usually "USB Serial" or "CP210x") and click Connect.

STEP 03

### Confirm the installation

The webflasher automatically detects the device and shows a confirmation dialog: "Confirm Installation — Do you want to install NastyThermostat Firmware v1.0.0?". Click Install.

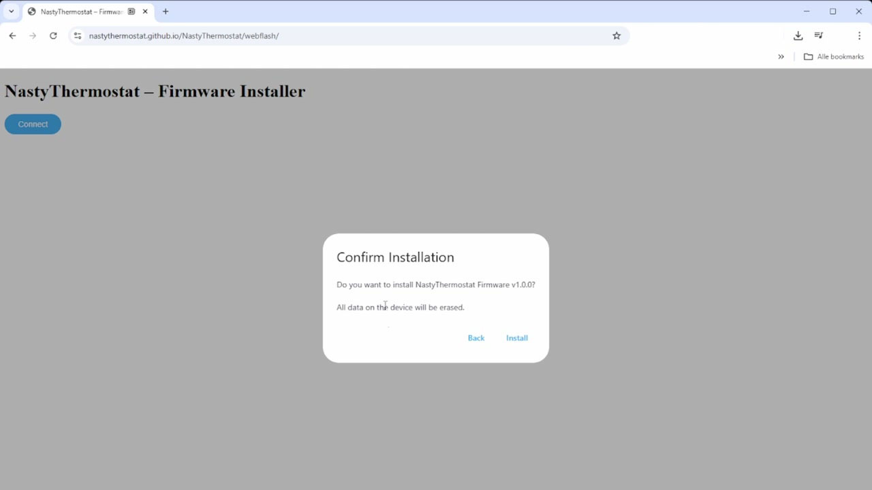
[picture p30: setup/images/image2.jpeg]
Confirm Installation dialog


STEP 04

### Wait for the installation

The firmware is now being written to the device. This takes approximately 1–2 minutes. Keep the browser page visible — this prevents slowdown.

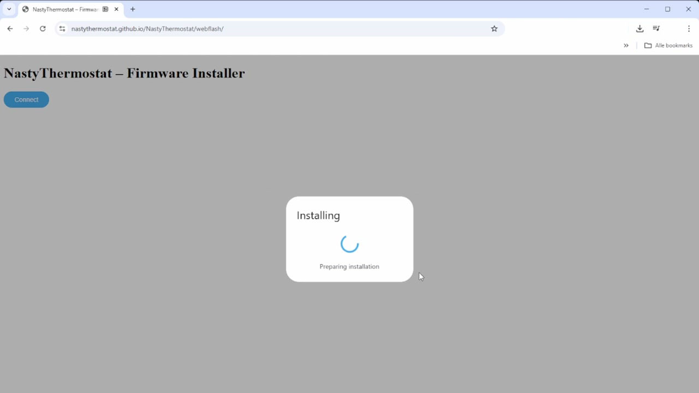
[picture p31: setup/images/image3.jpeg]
Installing firmware


⚠ Do not disconnect the USB during installation.

STEP 05

### Installation complete

Afterwards the menu appears with two options: "Install NastyThermostat Firmware" and "Logs & Console". Click Logs & Console to verify the device booted correctly.

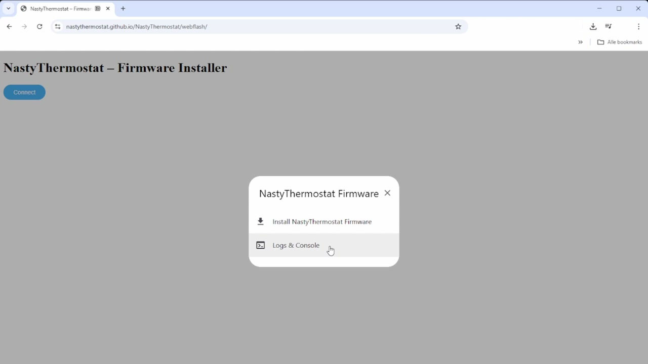
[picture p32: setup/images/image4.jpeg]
Post-install menu


STEP 06

### Check the logs

The logs show the boot messages of the ESP32. At the bottom "Starting Web Portal" appears — this means the NastyThermostat has created its own WiFi network for configuration.

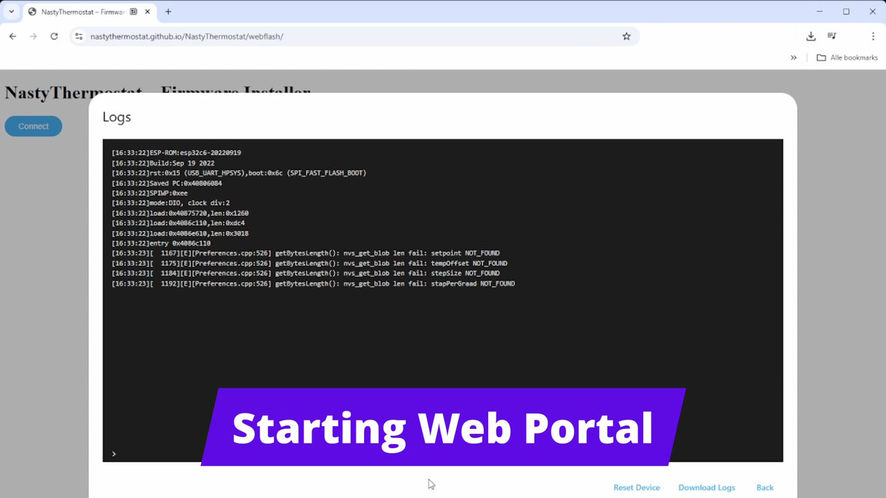
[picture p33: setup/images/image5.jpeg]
Boot logs — Starting Web Portal


Part 2 — Configuring WiFi

STEP 07

### Connect to the NastyThermostat network

Open the WiFi settings on your computer or phone. You will see a network appear named "NastyThermostatE08898" (the last digits are the MAC address of your device). Click Connect.

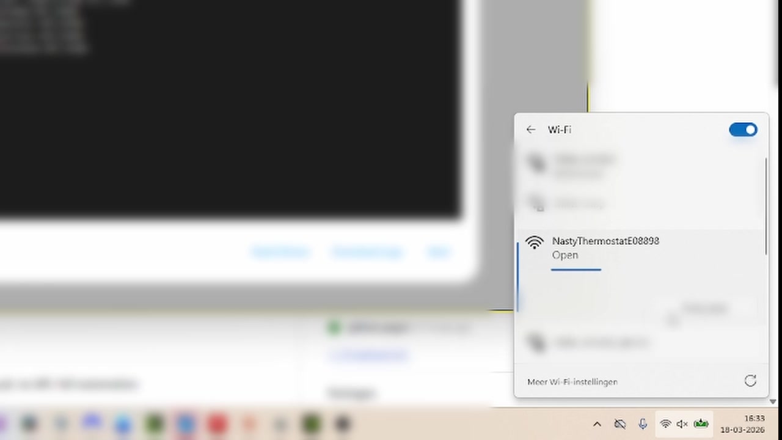
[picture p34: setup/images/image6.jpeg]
WiFi network appearing


💡 The network has no password and no internet access — this is normal.

STEP 08

### Open the configuration portal

Windows automatically shows a notification "Action required, no internet" with the button "Open browser and connect". Click this, or navigate manually to 192.168.4.1 in your browser.

You now see the WiFiManager portal of the NastyThermostat. Click Configure WiFi to continue.

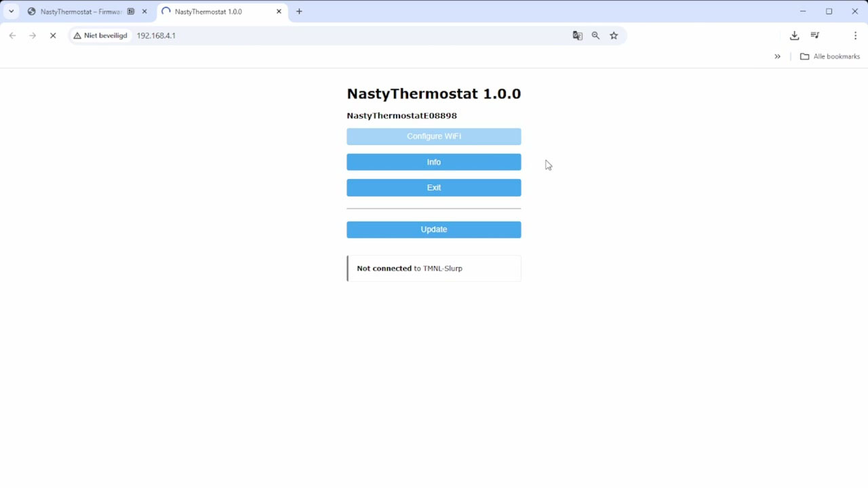
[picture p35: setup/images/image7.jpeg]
WiFiManager portal


Part 3 — Configuring Settings

STEP 09

### WiFi and basic MQTT settings

The configuration page shows a list of available WiFi networks at the top. Below is a description of all fields:

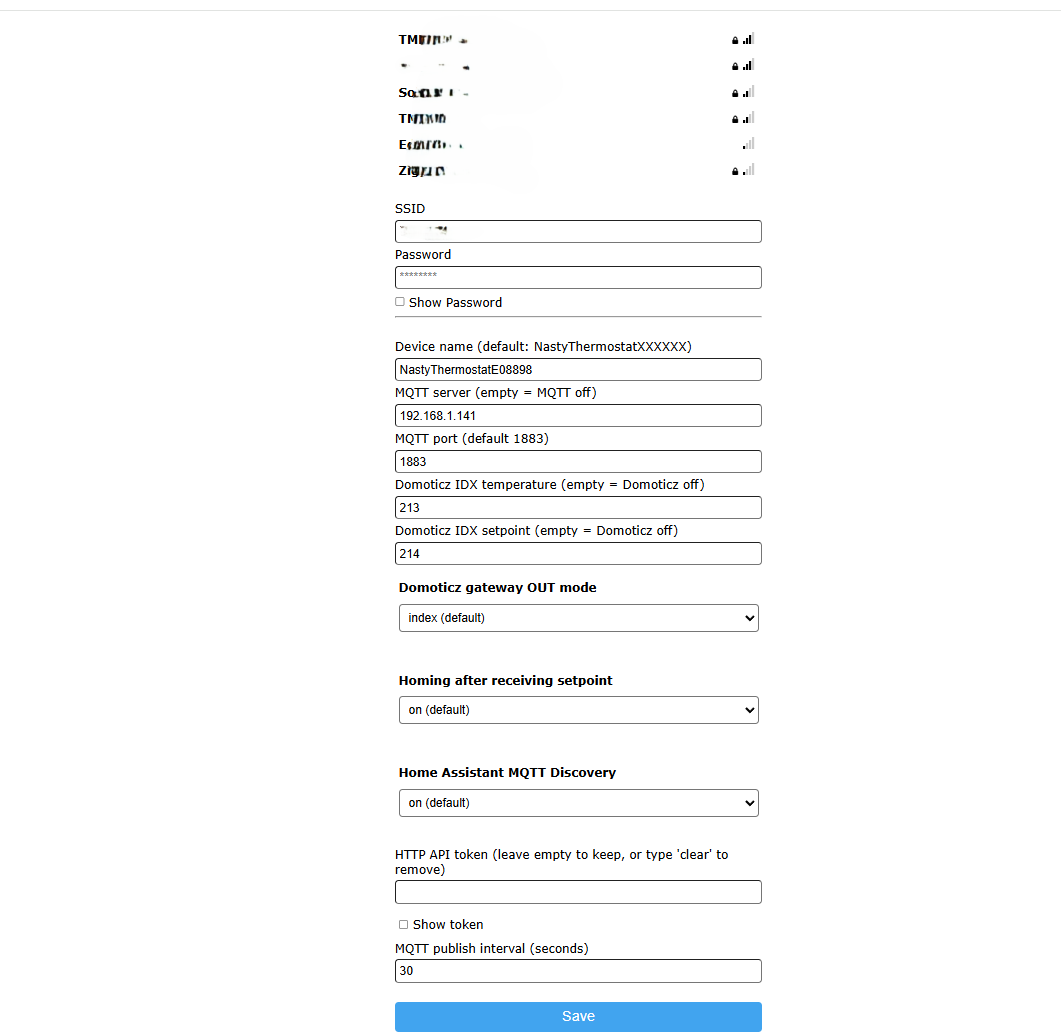
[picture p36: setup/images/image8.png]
Configuration page


SSID / Password

Select your WiFi network from the list and enter the password. The NastyThermostat will connect to it after saving.

Device name

Default: NastyThermostatXXXXXX

The name of the device. XXXXXX represents the last 6 characters of the MAC address. Used as the base for MQTT topics (e.g. NastyThermostatE08898/out/temp) and as the hostname on the network. When using multiple thermostats, each must have a unique name.

MQTT server

Default: Empty = MQTT disabled

IP address or hostname of your MQTT broker (e.g. 192.168.1.141). If this field is empty, no MQTT connection is made and Domoticz and Home Assistant will also not be active.

MQTT port

Default: 1883

Port number of the MQTT broker. Usually 1883 (unencrypted). Only change this if your broker runs on a non-standard port.

Domoticz IDX temperature

Default: Empty = Domoticz disabled

The IDX number of the temperature virtual device in Domoticz. The measured temperature is published to this IDX. Both this and the IDX setpoint must be filled in to activate Domoticz integration.

Domoticz IDX setpoint

Default: Empty = Domoticz disabled

The IDX number of the setpoint virtual device in Domoticz (type Thermostat Setpoint). The NastyThermostat listens on this IDX for setpoint changes from Domoticz, and publishes the current setpoint back.

Domoticz gateway OUT mode

Default: index

Determines the format used when the NastyThermostat publishes to Domoticz.

indexstandard Domoticz JSON format with idx, nvalue, svalue (recommended)

flatsimplified format, only for special Domoticz configurations

Homing after receiving setpoint

Default: on

Determines what happens when a new setpoint is received via MQTT, API or Domoticz.

onthe motor first returns to the zero position (homing) for maximum accuracy, then moves to the new setpoint

offthe motor moves directly to the new setpoint with a short "wake-jiggle" to activate the Nest thermostat (faster, slightly less accurate)

Home Assistant MQTT Discovery

Default: on

Determines whether the NastyThermostat automatically sends an MQTT Discovery message.

onHome Assistant automatically recognises the device as a climate entity (temperature + setpoint visible in HA without manual configuration)

offno automatic HA integration

HTTP API token

Default: Empty = current token unchanged

Security token for the HTTP API (POST requests). Without a token, only GET requests are possible (read-only). Enter a password of your choice to secure write access. Type clear to remove the token and block write access.

MQTT publish interval

Default: 30 seconds

How often the NastyThermostat publishes the temperature and setpoint to MQTT. Minimum 1 second. Lower values result in more network traffic and slightly higher power consumption.

STEP 11

### Save

Click the Save button. The NastyThermostat saves the settings and attempts to connect to your WiFi network.

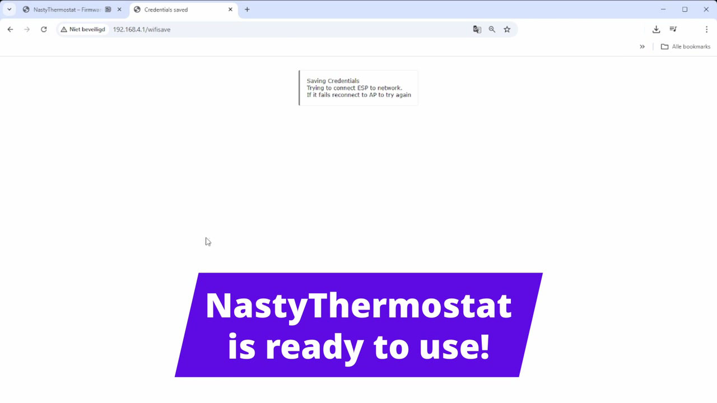
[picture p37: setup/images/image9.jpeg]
Credentials saved


Your computer disconnects from the NastyThermostat network and the NastyThermostat automatically connects to your own WiFi. The NastyThermostat is now ready to use.

💡 If the connection fails, the NastyThermostat network reappears and you can re-enter the settings.

NastyThermostat — nastythermostat.cc Build guide (https://nastythermostat.cc/build) · 3D models (https://nastythermostat.cc/3d-models) · Setup & Flash (https://nastythermostat.cc/setup) · Webflash (https://nastythermostat.cc/webflash) · GitHub (https://github.com/nastythermostat/NastyThermostat)

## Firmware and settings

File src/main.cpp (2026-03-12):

/*
  === Nest Stepper + TFT Menu (ESP32-C6, ST7789) ================================
  v1.0.0 - First public release

  Changes in v1.0.0:
  - First public release on GitHub.
  - WiFi credentials removed from arduino_secrets.h.
  - homingNest: added 15-second safety timeout to moveStepperTo() so the motor
    stops automatically if the mechanical end-stop is missed.
  - handleApiRequest: fixed mixed tabs/spaces indentation in POST token-check block.

  v0.3.13 (pre-release)

  v0.3.12

  Changes in v0.3.12:
  - Device naming is now unique by default: "NastyThermostat" + last 6 chars of MAC.
  - Device name is configurable from the AP/WiFiManager settings page.
  - MQTT base topics are now derived from the configured device name, so multiple
    thermostats no longer collide on the same topics.
  - Home Assistant discovery labels/device metadata now follow the configured
    device name for clear per-device identification.
  - AP settings page now always shows all custom parameters, also on first setup.

  Changes in v0.3.11:
  - HTTP API token: use the token saved from AP settings (Preferences) for /api, instead of the build-time API_TOKEN.
    * If no token is configured: GET /api is allowed, POST /api is disabled.
    * If a token is configured: token is required for both GET (query ?token=) and POST (JSON field token).
  - Stepper motion: reduce how often we yield to the WiFi stack during long blocking moves to prevent micro-pauses.

  - Stepper motion smoothness: removed full-screen TFT redraws during blocking
    motor moves (homing / moving to temperature). Display is woken but the heavy
    redraw is deferred, preventing stutter.
  - Home Assistant: added retained "action" topic (heating/idle) and publish it
    on temperature and setpoint updates.
  - Home Assistant setpoint stability: target setpoint state is published as
    retained when HA discovery is enabled, preventing HA from jumping back to an
    older retained value.

  (v0.3.8 changes)
  - Home Assistant MQTT Discovery (optional): when MQTT is enabled, the device can
    publish a retained MQTT Discovery config so Home Assistant automatically adds a
    climate entity (setpoint + current temperature). Toggle via AP settings:
    "Home Assistant discovery (on/off)".
  - Nest wake behavior when "Homing after receiving setpoint" is OFF:
      - changed the wake-jiggle to 0.5°C (down & back)
      - uses the fast homing speed profile for this short jiggle
    This makes the movement feel more natural while still waking the Nest.
*/

#include <Arduino.h>
#include <ctype.h>
#include <math.h>
#include <stdlib.h>

#include <Adafruit_GFX.h>
#include <Adafruit_ST7789.h>
#include <SPI.h>

#include <AccelStepper.h>
#include <OneWireNg_CurrentPlatform.h>
#include <Preferences.h>
#include <WiFi.h>
#include <PubSubClient.h>
#include <ArduinoJson.h>
#include <WebServer.h>

#include <WiFiManager.h>

#include "arduino_secrets.h"

// ===================== FIRMWARE INFO ========================================
#define FW_NAME    "NastyThermostat"
#define FW_VERSION "1.0.0"
#define HA_FW_NAME "Nasty"
#define HA_CLIMATE_NAME "Thermostat"

// Requested AP name
#define AP_SSID_PRIMARY  "NastyThermostat"
#define AP_SSID_FALLBACK "NastyESP32"

// Preference key to reboot into portal mode
#define CFG_NAMESPACE "config"
#define KEY_PORTAL_REQUEST "portalReq"
#define KEY_DZ_OUT_MODE   "dzOutMode"
#define KEY_HA_DISC       "haDisc"
#define KEY_HOME_AFTER_RX "homeAfterRx"
#define KEY_DEVICE_NAME   "devName"

// ===================== TFT PINNING (ESP32-C6 LCD 1.47) ======================
#define TFT_CS    14
#define TFT_DC    15
#define TFT_RST   21
#define TFT_BL    22
#define TFT_MISO  -1
#define TFT_MOSI  6
#define TFT_SCLK  7

Adafruit_ST7789 tft = Adafruit_ST7789(TFT_CS, TFT_DC, TFT_RST);

// ===================== WIFI/MQTT/API ========================================
WiFiClient espClient;
PubSubClient client(espClient);
WebServer server(80);

WiFiManager wm;
volatile bool shouldSaveConfig = false;

// MQTT runtime enable (disabled if mqttServer is empty)
bool mqttEnabled = true;

// ===================== STEPPER / ENCODER / DS18B20 ==========================
#define dirPin 3
#define stepPin 2
#define enablePin 5
#define motorInterfaceType 1

#define encoderPinA 0
#define encoderPinB 1
#define encoderButtonPin 4

#define ONE_WIRE_PIN 9
#define ENABLE_PULLUP true

AccelStepper stepper(motorInterfaceType, stepPin, dirPin);
OneWireNg_CurrentPlatform ow(ONE_WIRE_PIN, ENABLE_PULLUP);

// Preferences
Preferences prefs;     // setpoint namespace
Preferences prefsCfg;  // config namespace

// ===================== RUNTIME CONFIG =======================================
struct AppConfig {
  String deviceName = "";
  String topicBase  = MQTT_TOPIC_BASE;

  // MQTT
  String mqttServer = MQTT_SERVER;
  uint16_t mqttPort = MQTT_PORT;


// HTTP API
// If empty: GET /api allowed, POST /api disabled (no writes).
// If set: token required for GET and POST.
String apiToken = API_TOKEN;


  // Topics
  String topicTemp        = MQTT_TOPIC_TEMP;
  String topicSetpoint    = MQTT_TOPIC_SETPOINT;
  String topicSetpointCmd = MQTT_TOPIC_SETPOINT_CMD;
  String topicSetpointIn  = "domoticz/out"; // computed from domoticzOutMode + idx
  String topicDomoticzIn  = MQTT_TOPIC_DOMOTICZ_IN;

  // Domoticz MQTT Gateway OUT mode: "index" or "flat"
  String domoticzOutMode  = "index";

  // Domoticz IDX
  int domoticzIdxSetpoint = 0;      // 0 = disabled
  int domoticzIdxTemp     = 0;      // 0 = disabled

  // Behavior
  bool homingAfterReceivingSetpoint = true;

  // Home Assistant (MQTT Discovery)
  bool homeAssistantDiscovery = true;

  // Interval
  uint16_t mqttPublishIntervalSec = 30;
};

AppConfig cfg;

// ===================== VARIABELEN ===========================================
volatile int  encoderDirection      = 0;
volatile bool encoderMovedMenu      = false;
volatile bool encoderMovedSetpoint  = false;
volatile bool buttonPressed         = false;

float Setpoint = 18.5;
float stepSize = 0.1;
float lastMeasuredTemp = 0.0;
bool hasTempReading = false;   // becomes true after first successful DS18B20 read
unsigned long lastActionPublishMs = 0; // periodic refresh for HA action topic


bool menuActive    = false;
bool subMenuActive = false;
int  menuIndex     = 0;

// submenu state
float offsetMenuValue = 0.0;
float calibrationStepsValue = 0.0;
int   stepSizeIndex = 0;

float temperatureOffset = 0.0;

unsigned long lastTempRequest = 0;
const unsigned long conversionTime = 750;
bool tempRequested = false;

unsigned long lastSetpointChange = 0;
const unsigned long setpointSaveDelay = 4000; // ms

// Stepper idle
unsigned long lastStepperMovement = 0;
const unsigned long stepperTimeout = 4000; // ms
bool stepperEnabled = true;

static inline void enableStepperDriver() {
  digitalWrite(enablePin, LOW); // DRV8825 enable is LOW
  stepperEnabled = true;
}

static inline void disableStepperDriver() {
  digitalWrite(enablePin, HIGH); // disable
  stepperEnabled = false;
}

// Overbrenging & microstepping
const int   stepperPulleyTeeth      = 20;
const int   nestPulleyTeeth         = 138;
const float microstepFactor          = 0.03125;    // 1/32
const int   stepsPerRevolutionMotor = 200;

// --- speed profiles ---
const float speedNormal  = 40.0;
const float accelNormal  = 20.0;
const float speedHoming  = 400.0;
const float accelHoming  = 300.0;
const float speedRotary  = 120.0;
const float accelRotary  = 80.0;

// MQTT publish interval (runtime)
unsigned long lastMqttPublish = 0;
unsigned long mqttInterval = 30000;

// publish tracking
float lastPublishedSetpoint = -999;
float lastPublishedTemp     = -999;

// --- loop/echo guards ---
// Some MQTT bridges (notably the Domoticz MQTT gateway) will echo a value we just
// published back on their OUT topic. If we treat that echo as a new command we can
// end up re-processing the same setpoint (and possibly re-homing / re-moving).
//
// Strategy:
// - When we publish a setpoint to Domoticz (domoticz/in), remember value + timestamp.
// - When a Domoticz OUT message arrives, ignore it if it matches the last value we
//   sent within a short guard window.
//
// This keeps things snappy while still allowing real external changes to flow through.
const unsigned long SETPOINT_ECHO_GUARD_MS = 1200;
float lastSentDomoticzSetpoint = -999;
unsigned long lastSentDomoticzSetpointMs = 0;
unsigned long lastSetpointStatePublishMs = 0;
bool  publishSetpointOnBootPending = true;

// Home Assistant "action" (heating/idle) publishing
// We keep it retained so HA doesn't bounce on reconnect.
String lastPublishedAction = "";

// Derived values
long  stepsPerMotorRevolution = (long)(stepsPerRevolutionMotor / microstepFactor);
float gearRatio             = (float)nestPulleyTeeth / (float)stepperPulleyTeeth;
long  stepsPerNestRevolution  = (long)(stepsPerMotorRevolution * gearRatio);

// Nest operating range
const float minNestTempC = 9.0;
const float maxNestTempC = 32.0;

// Encoder settle
const unsigned long ENCODER_SETTLE_MS = 1000;
bool pendingSetpointMove = false;

// External setpoint apply (MQTT/API/Domoticz) - optional "wake" jiggle.
// When homing-after-receive is OFF, we can briefly move 1°C down and back to
// "wake" the Nest before moving to the new setpoint.
enum ExternalMoveState {
  EXT_NONE = 0,
  EXT_WAKE_DOWN,
  EXT_WAKE_BACK,
  EXT_MOVE_NEW
};
ExternalMoveState extMoveState = EXT_NONE;
long extTargetDown = 0;
long extTargetBack = 0;
long extTargetNew  = 0;

// Remember where we came from for external moves
float extOldSetpoint = 0.0f;
float extNewSetpoint = 0.0f;

// steps/°C opslag (full-step basis)
float stepsPerDegreeBase;  // full-step opslag
float stepsPerDegreeCalc;   // omgerekend naar microsteps
float stepsPerDegreeNest;   // effectief gebruikt

// ===================== UI / DISPLAY STATE ===================================
unsigned long lastInteractionMs = 0;
bool screenOn = true;
const unsigned long SCREEN_TIMEOUT_MS = 15000;

// Allow stepper code to keep the screen awake.
// We disable this during boot-homing and during WiFiManager portal/AP mode,
// so the display stays off until the device is ready.
bool screenWakeAllowed = true;

// redraw throttle
float  lastShownSetpoint = -1000.0;
float  lastShownTemp     = -1000.0;
bool   lastWifiConnected = false;

// ===================== MENU ITEMS ===========================================
const int menuItemCount = 7;
const char* menuItems[menuItemCount] = {
  "1. Homing",
  "2. Temperature offset",
  "3. Steps/degree",
  "4. Step size",
  "5. WiFi setup",
  "6. Status",
  "7. Back"
};
const int menuStartY = 15;
const int menuLineHeight = 24;
const int menuIndentX = 10;

// Stapgroottes
const int STEP_SIZE_COUNT = 4;
const float stepSizeOptions[STEP_SIZE_COUNT] = {0.1, 0.2, 0.5, 1.0};

// WiFi submenu
int wifiSubIndex = 0;
const int wifiSubCount = 2;
const char* wifiSubItems[wifiSubCount] = {
  "Start WiFi portal (reboot)",
  "Back"
};


// ===================== PROTOTYPES ===========================================
void IRAM_ATTR handleButton();

void requestTemperature();
float readTemperature();
void primeTemperatureReading();


void saveSetpoint();

void homingNest(bool goToSetpoint = true);
void setNestToTemperature(float targetTemp);
void moveStepperTo(long absolutePosition, unsigned long timeoutMs = 0);

void setStepperProfileNormal();
void setStepperProfileRotary();
void setStepperProfileHoming();

void reconnectMQTT();
void mqttCallback(char* topic, byte* payload, unsigned int length);
void setupMQTT();
void mqttLoop();
void publishTemperature();
void publishSetpoint(bool force);

void publishDomoticzTemp();
void publishDomoticzSetpoint();

// Home Assistant discovery (MQTT)
void publishAvailability(bool online);
void publishHomeAssistantDiscovery();
void publishHomeAssistantModeHeat();
void publishHomeAssistantAction();

// Home Assistant topic helpers (forward declarations)
static String haTopicAvailability();
static String haTopicModeState();
static String haTopicModeCommand();
static String haTopicAction();

void checkEncoder();
void handleMenu();
void drawInfo();
void drawMenu();
void drawWifiIcon(bool connected);

void drawSubmenuOffset();
void drawSubmenuSteps();
void drawSubmenuStepSize();
void drawSubmenuWiFi();
void drawSubmenuStatus();

void wakeScreen();

void applyExternalSetpoint(float newSetpoint, const char* sourceTag);
void processExternalMoveState();

void handleApiRequest();
void handleSerialCommands();

void loadConfig();
void saveConfig();
bool runWiFiManagerPortal(bool forcedPortal, uint16_t portalTimeoutSec);
bool setupWiFiAuto();
void printBanner();

void requestPortalAndReboot();
bool consumePortalRequest();
static String defaultDeviceName();
static void rebuildDerivedTopics();
static String portalApName();
static String haPrettyDeviceName();

// ===================== WiFiManager callbacks ================================
void onSaveConfig() { shouldSaveConfig = true; }

static String macHex12() {
  char macBuf[13];
  uint64_t mac = ESP.getEfuseMac();
  snprintf(macBuf, sizeof(macBuf), "%012llX", (unsigned long long)(mac & 0xFFFFFFFFFFFFULL));
  return String(macBuf);
}

static String macSuffix6() {
  String mac = macHex12();
  if (mac.length() < 6) return "000000";
  return mac.substring(mac.length() - 6);
}

static String defaultDeviceName() {
  return String(FW_NAME) + macSuffix6();
}
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
void loop() {
  static unsigned long lastCheck = 0;
  if (millis() - lastCheck > 1) {
    checkEncoder();
    handleMenu();
    lastCheck = millis();
  }

  // Re-print banner after a short delay so Serial Monitor won't miss it
  static bool bannerReprinted = false;
  if (!bannerReprinted && millis() > 10000) {
    printBanner();
    bannerReprinted = true;
  }
  handleSerialCommands(); //? in serial shows banner again

  mqttLoop();
  server.handleClient();

// Outside the menu: adjust setpoint (only update value while turning)
// Outside the menu: adjust setpoint
static bool rotaryMoveActive = false;

// 1) While turning: update setpoint value and mark change time
if (!menuActive && !subMenuActive && encoderMovedSetpoint) {
  encoderMovedSetpoint = false;

  Setpoint += encoderDirection * stepSize;
  Setpoint = constrain(Setpoint, minNestTempC, maxNestTempC);

  lastSetpointChange = millis();
  pendingSetpointMove = true;
}

// 2) Start (or update) motion shortly after user pauses (fast, natural)
if (!menuActive && !subMenuActive && pendingSetpointMove &&
    (millis() - lastSetpointChange >= ENCODER_SETTLE_MS)) {

  // Start motion profile once
  if (!rotaryMoveActive) {
    setStepperProfileRotary();
    rotaryMoveActive = true;
  }

  // Always update target to latest Setpoint (no save yet)
  long targetSteps = lround((Setpoint - minNestTempC) * stepsPerDegreeNest);
  stepper.moveTo(targetSteps);

  pendingSetpointMove = false; // cleared until next encoder tick
}

// 3) Save setpoint after a longer pause (flash friendly)
if (!menuActive && !subMenuActive && (lastSetpointChange != 0) &&
    (millis() - lastSetpointChange > setpointSaveDelay)) {

  saveSetpoint();
  lastSetpointChange = 0;

  publishSetpoint(true);
  // keep rotary profile while moving; we switch back when done
}

// 4) When motion finished: restore normal profile
if (rotaryMoveActive && stepper.distanceToGo() == 0) {
  setStepperProfileNormal();
  rotaryMoveActive = false;
}

  // External setpoint state machine (MQTT/API/Domoticz)
  processExternalMoveState();

  // Temperature reading cycle
  if (!menuActive && !subMenuActive) {
    unsigned long now = millis();
    if (tempRequested && (now - lastTempRequest >= conversionTime)) {
      lastMeasuredTemp = readTemperature();
      hasTempReading = true;
      tempRequested = false;
      requestTemperature();
    }
  }

  // Stepper power management
  if (stepper.distanceToGo() != 0) {
    // Keep display on while the motor is moving (homing / API / encoder)
    wakeScreen();
    if (!stepperEnabled) {
      enableStepperDriver();
    }
    lastStepperMovement = millis();
  }

  stepper.run();

  if (stepperEnabled && (millis() - lastStepperMovement > stepperTimeout)) {
    disableStepperDriver();
  }

  // Screen backlight auto-off
  if (screenOn && (millis() - lastInteractionMs > SCREEN_TIMEOUT_MS)) {
    digitalWrite(TFT_BL, LOW);
    screenOn = false;
  }

  // Refresh main screen on change
  if (!menuActive && !subMenuActive) {
    bool wifiConn = (WiFi.status() == WL_CONNECTED);

    int sp10 = (int)lround(Setpoint * 10.0);
    int tm10 = (int)lround(lastMeasuredTemp * 10.0);
    int ls10 = (int)lround(lastShownSetpoint * 10.0);
    int lt10 = (int)lround(lastShownTemp * 10.0);

    if (sp10 != ls10 || tm10 != lt10 || wifiConn != lastWifiConnected) {
      drawInfo();
    }
  }
}

// ===================== ENCODER / BUTTON ====================================
void checkEncoder() {
  static uint8_t lastState = 0;
  static int8_t delta = 0;

  uint8_t clk = digitalRead(encoderPinA);
  uint8_t dt  = digitalRead(encoderPinB);
  uint8_t currentState = (clk << 1) | dt;

  if (currentState != lastState) {
    if (!screenOn) {
      lastInteractionMs = millis();
      digitalWrite(TFT_BL, HIGH);
      screenOn = true;
      lastState = currentState;
      delta = 0;
      return;
    }

    if ((lastState == 0b00 && currentState == 0b01) ||
        (lastState == 0b01 && currentState == 0b11) ||
        (lastState == 0b11 && currentState == 0b10) ||
        (lastState == 0b10 && currentState == 0b00)) {
      delta++;
    } else {
      delta--;
    }

    if (abs(delta) >= 2) {
      encoderDirection = (delta > 0) ? -1 : 1;
      lastInteractionMs = millis();

      if (menuActive || subMenuActive) encoderMovedMenu = true;
      else encoderMovedSetpoint = true;

      delta = 0;
    }
    lastState = currentState;
  }
}

void IRAM_ATTR handleButton() {
  static unsigned long lastPress = 0;
  unsigned long now = millis();

  if ((now - lastPress) > 250) {
    buttonPressed = true;
    lastPress = now;
  }
}

// ===================== TEMPERATURE =========================================
void requestTemperature() {
  ow.reset();
  ow.writeByte(0xCC);
  ow.writeByte(0x44);
  lastTempRequest = millis();
  tempRequested = true;
}

float readTemperature() {
  ow.reset();
  ow.writeByte(0xCC);
  ow.writeByte(0xBE);

  uint8_t data[9];
  for (int i = 0; i < 9; i++) data[i] = ow.readByte();

  int16_t raw = (data[1] << 8) | data[0];
  float tempC = raw / 16.0;

  return tempC + temperatureOffset;
}

// Do one blocking temperature conversion at boot so lastMeasuredTemp is valid
// before we publish HA "action" (heating/idle) and before the screen/UI comes up.
// This prevents a temporary 0.00°C from causing a false "heating" state.
void primeTemperatureReading() {
  requestTemperature();
  unsigned long start = millis();
  while (millis() - start < conversionTime) {
    delay(5);
  }
  lastMeasuredTemp = readTemperature();
  hasTempReading = true;

  // Start the normal async cycle again
  tempRequested = false;
  requestTemperature();
}


// ===================== FLASH OPSLAG ========================================
void saveSetpoint() {
  prefs.putFloat("setpoint", Setpoint);
  Serial.print("Setpoint saved: ");
  Serial.println(Setpoint, 1);
}

// ===================== STEPPER FUNCTIES =====================================
void homingNest(bool goToSetpoint) {
  // Keep display awake during homing (can be suppressed via screenWakeAllowed)
  wakeScreen();
  setStepperProfileHoming();

  long stepsForHoming = (long)(stepsPerNestRevolution * 0.75);
  delay(200);
  // 15-second timeout: prevents infinite run if the mechanical stop is missed.
  moveStepperTo(stepper.currentPosition() - stepsForHoming, 15000UL);

  stepper.setCurrentPosition(0);
  delay(200);

  setStepperProfileNormal();
  if (goToSetpoint) {
    setNestToTemperature(Setpoint);
  }
}

void setNestToTemperature(float targetTemp) {
  setStepperProfileNormal();

  targetTemp = constrain(targetTemp, minNestTempC, maxNestTempC);
  float currentTempC = minNestTempC + (stepper.currentPosition() / stepsPerDegreeNest);

  float deltaTempC = targetTemp - currentTempC;
  long steps = lround(deltaTempC * stepsPerDegreeNest);
  if (steps != 0) moveStepperTo(stepper.currentPosition() + steps);
}

void moveStepperTo(long absolutePosition, unsigned long timeoutMs) {
  // Any motor movement should wake the display (even without user interaction)
  // IMPORTANT:
  // We intentionally avoid heavy TFT redraws while stepping.
  // A full-screen redraw (fillScreen + big text) can take multiple milliseconds
  // over SPI and will starve AccelStepper::run(), causing jerky movement.
  wakeScreen();
  // Show something *once* before the move starts.
  if (!menuActive && !subMenuActive) {
    drawInfo();
  }
  if (!stepperEnabled) {
    enableStepperDriver();
  }
  stepper.moveTo(absolutePosition);
  // Custom run loop so we can keep the display awake during the (blocking) move.
  unsigned long lastYieldUs = micros();
  unsigned long startMs = millis();
  while (stepper.distanceToGo() != 0) {
    stepper.run();
    wakeScreen();

    // Give the WiFi stack some time, but NOT on every iteration.
    // Yielding too often can introduce tiny pauses during long moves.
    unsigned long nowUs = micros();
    if ((nowUs - lastYieldUs) > 2000UL) { // ~2ms
      yield();
      lastYieldUs = nowUs;
    }

    // Safety timeout: abort if the move takes too long (e.g. mechanical stop missed).
    if (timeoutMs > 0 && (millis() - startMs) >= timeoutMs) {
      stepper.stop();
      Serial.println("⚠️ moveStepperTo: timeout reached, stopping motor.");
      break;
    }
  }
  lastStepperMovement = millis();
}
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
